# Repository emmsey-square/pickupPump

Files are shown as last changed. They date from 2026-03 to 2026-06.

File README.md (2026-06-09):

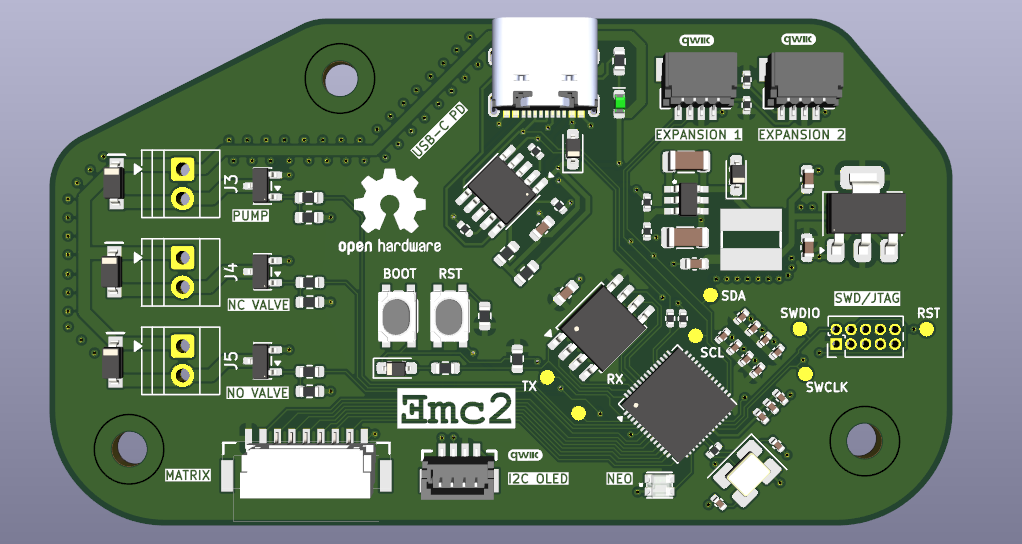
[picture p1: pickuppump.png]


#   PickupPump- a Vacuum Pickup Tool for SMD Components (In Progress)

##  Brief

I was a big fan of the Pixel Pump project by Robbin's and loving the idea, but wanting to create my own version to better suit my needs, as well as allow me to design a circuit board of my own, I started working on my very own version. 

## Design Choices 

- RP2350 for the main mcu as it's a new and interesting chip from Raspberry Pi with a very solid SDK for built for both of the RP2X chips. 
- USB-C port for power & USB paired with a CH224K USB PD sink chip to request 12V for all of the motors/pumps and a switching converter to step-down the voltage for the mcu
- JST connector for connection to an additional PCB outfitted with a 3x2 array of pushbuttons, with each one having functions such as toggling the current suction state of the pump, increasing/decreasing suction strength, etc.
- There's 3 Sparkfun Qwiic/ Stemma Qt compatible JST connectors onboard to connect to an Adafruit I2C OLED as well as to allow for expansions (ie. footswitch)
- Onboard Cortex debug header for debugging & programming

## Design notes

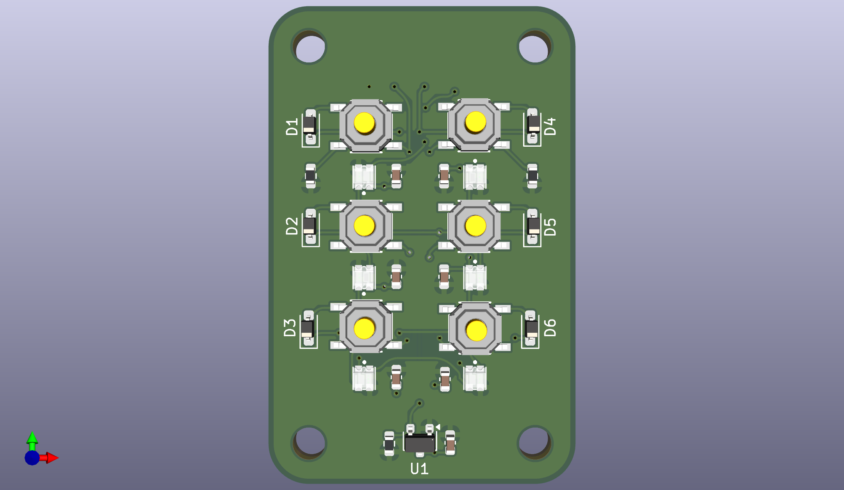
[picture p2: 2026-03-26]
pump_matrix/media/pump_matrix-front.png

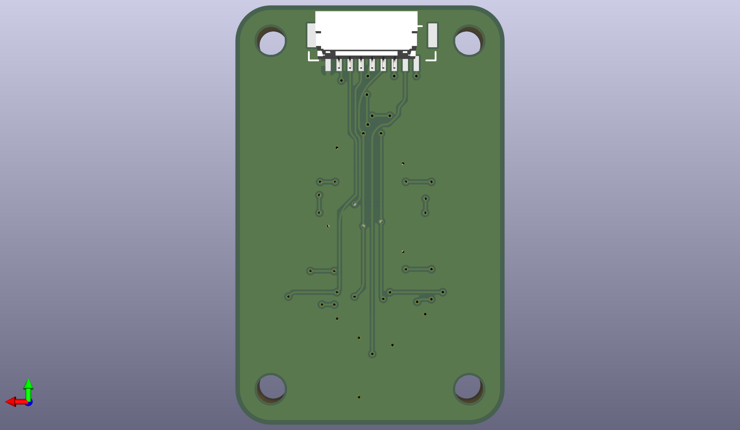
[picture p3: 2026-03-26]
pump_matrix/media/pump_matrix-back.png

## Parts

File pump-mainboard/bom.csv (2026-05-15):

Id | Designator | Footprint | Quantity | Designation | Supplier and ref
1 | TP5 | TestPoint-1.25mm | 1 | SDA
2 | C19 | C_1206_3216Metric | 1 | 4.7uF
3 | R16 | R_0402_1005Metric | 1 | 1k
4 | C10,C7,C8,C6,C9,C5,C4,C3,C11 | C_0402_1005Metric | 9 | 0.1uF
5 | L1 | Inductor_4.7x4.7mm | 1 | 15uH_5x5mm_1.0A
6 | Y1 | Crystal_SMD_EuroQuartz_MT-4Pin_3.2x2.5mm_HandSoldering | 1 | ABM8-272-T3
7 | TP1 | TestPoint-1.25mm | 1 | TX
8 | Q2,Q1,Q3 | SOT-23 | 3 | AO3400A
9 | D1,D8 | D_SOD-323_HandSoldering | 2 | 1N5819WS
10 | J3,J4,J5 | TerminalBlock_Xinya_XY308-2.54-2P_1x02_P2.54mm_Horizontal | 3 | Screw_Terminal_01x02
11 | C18 | C_1206_3216Metric | 1 | 2.2uF
12 | D4,D3,D2 | SOD-123 | 3 | 1N4007
13 | U5 | SOT23-6 | 1 | LMR14203
14 | C12,C13 | C_0402_1005Metric | 2 | 1.0uF
15 | C1,C2 | C_0402_1005Metric | 2 | 15pF
16 | R22,R23,R17,R24,R15 | R_0402_1005Metric | 5 | 10k
17 | R9,R3,R8,R11,R7,R6,R10,R4,R5 | R_0603_1608Metric | 9 | 10k
18 | J6 | JST_1x09_P1.25mm_Locking_Horizontal_SMD | 1 | BUTTON_MATRIX
19 | U2 | SOIC-8_5.3x5.3mm_P1.27mm | 1 | W25Q16JVSS
20 | U4 | SOT-223-3_TabPin2 | 1 | NCP1117-3.3
21 | J7 | JST_1x04_P1.0mm_Vertical_SMD | 1 | I2C_OLED
22 | D5 | LED_0603_1608Metric_Green | 1 | Green
23 | D7 | WS2812_2020 | 1 | WS2812B
24 | R1,R2 | R_0402_1005Metric | 2 | 27
25 | J9 | JST_1x04_P1.0mm_Horizontal_SMD | 1 | EXP2
26 | SW1 | Push_SMD_4.2x3.2mm | 1 | BOOT
27 | D6 | D_SOD-323_HandSoldering | 1 | NSR0320
28 | TP7 | TestPoint-1.25mm | 1 | RST
29 | C20 | C_0603_1608Metric | 1 | 47uF
30 | C14,C15 | C_0603_1608Metric | 2 | 10uF
31 | R20 | R_0402_1005Metric | 1 | 3.4k
32 | SW2 | Push_SMD_4.2x3.2mm | 1 | RESET
33 | R14,R12,R13 | R_0603_1608Metric | 3 | 1k
34 | TP2 | TestPoint-1.25mm | 1 | RX
35 | C16 | C_0603_1608Metric | 1 | 0.1uF
36 | J8 | JST_1x04_P1.0mm_Horizontal_SMD | 1 | EXP1
37 | U3 | SSOP-10-1EP_3.9x4.9mm_P1mm_EP2.1x3.3mm | 1 | CH224K
38 | R21 | R_0402_1005Metric | 1 | 1.02k
39 | C17 | C_0603_1608Metric | 1 | 1uF
40 | TP8 | TestPoint-1.25mm | 1 | SWDIO
41 | TP9 | TestPoint-1.25mm | 1 | SWCLK
42 | TP6 | TestPoint-1.25mm | 1 | SCL
43 | J2 | 2x05_P1.27mm | 1 | SWD
44 | U1 | QFN-56-1EP_7x7mm_P0.4mm_EP3.2x3.2mm | 1 | RP2040
45 | J1 | USB-C_16 | 1 | USB_C_Receptacle
46 | TP3 | TestPoint-1.25mm | 1 | D+
47 | TP4 | TestPoint-1.25mm | 1 | D-

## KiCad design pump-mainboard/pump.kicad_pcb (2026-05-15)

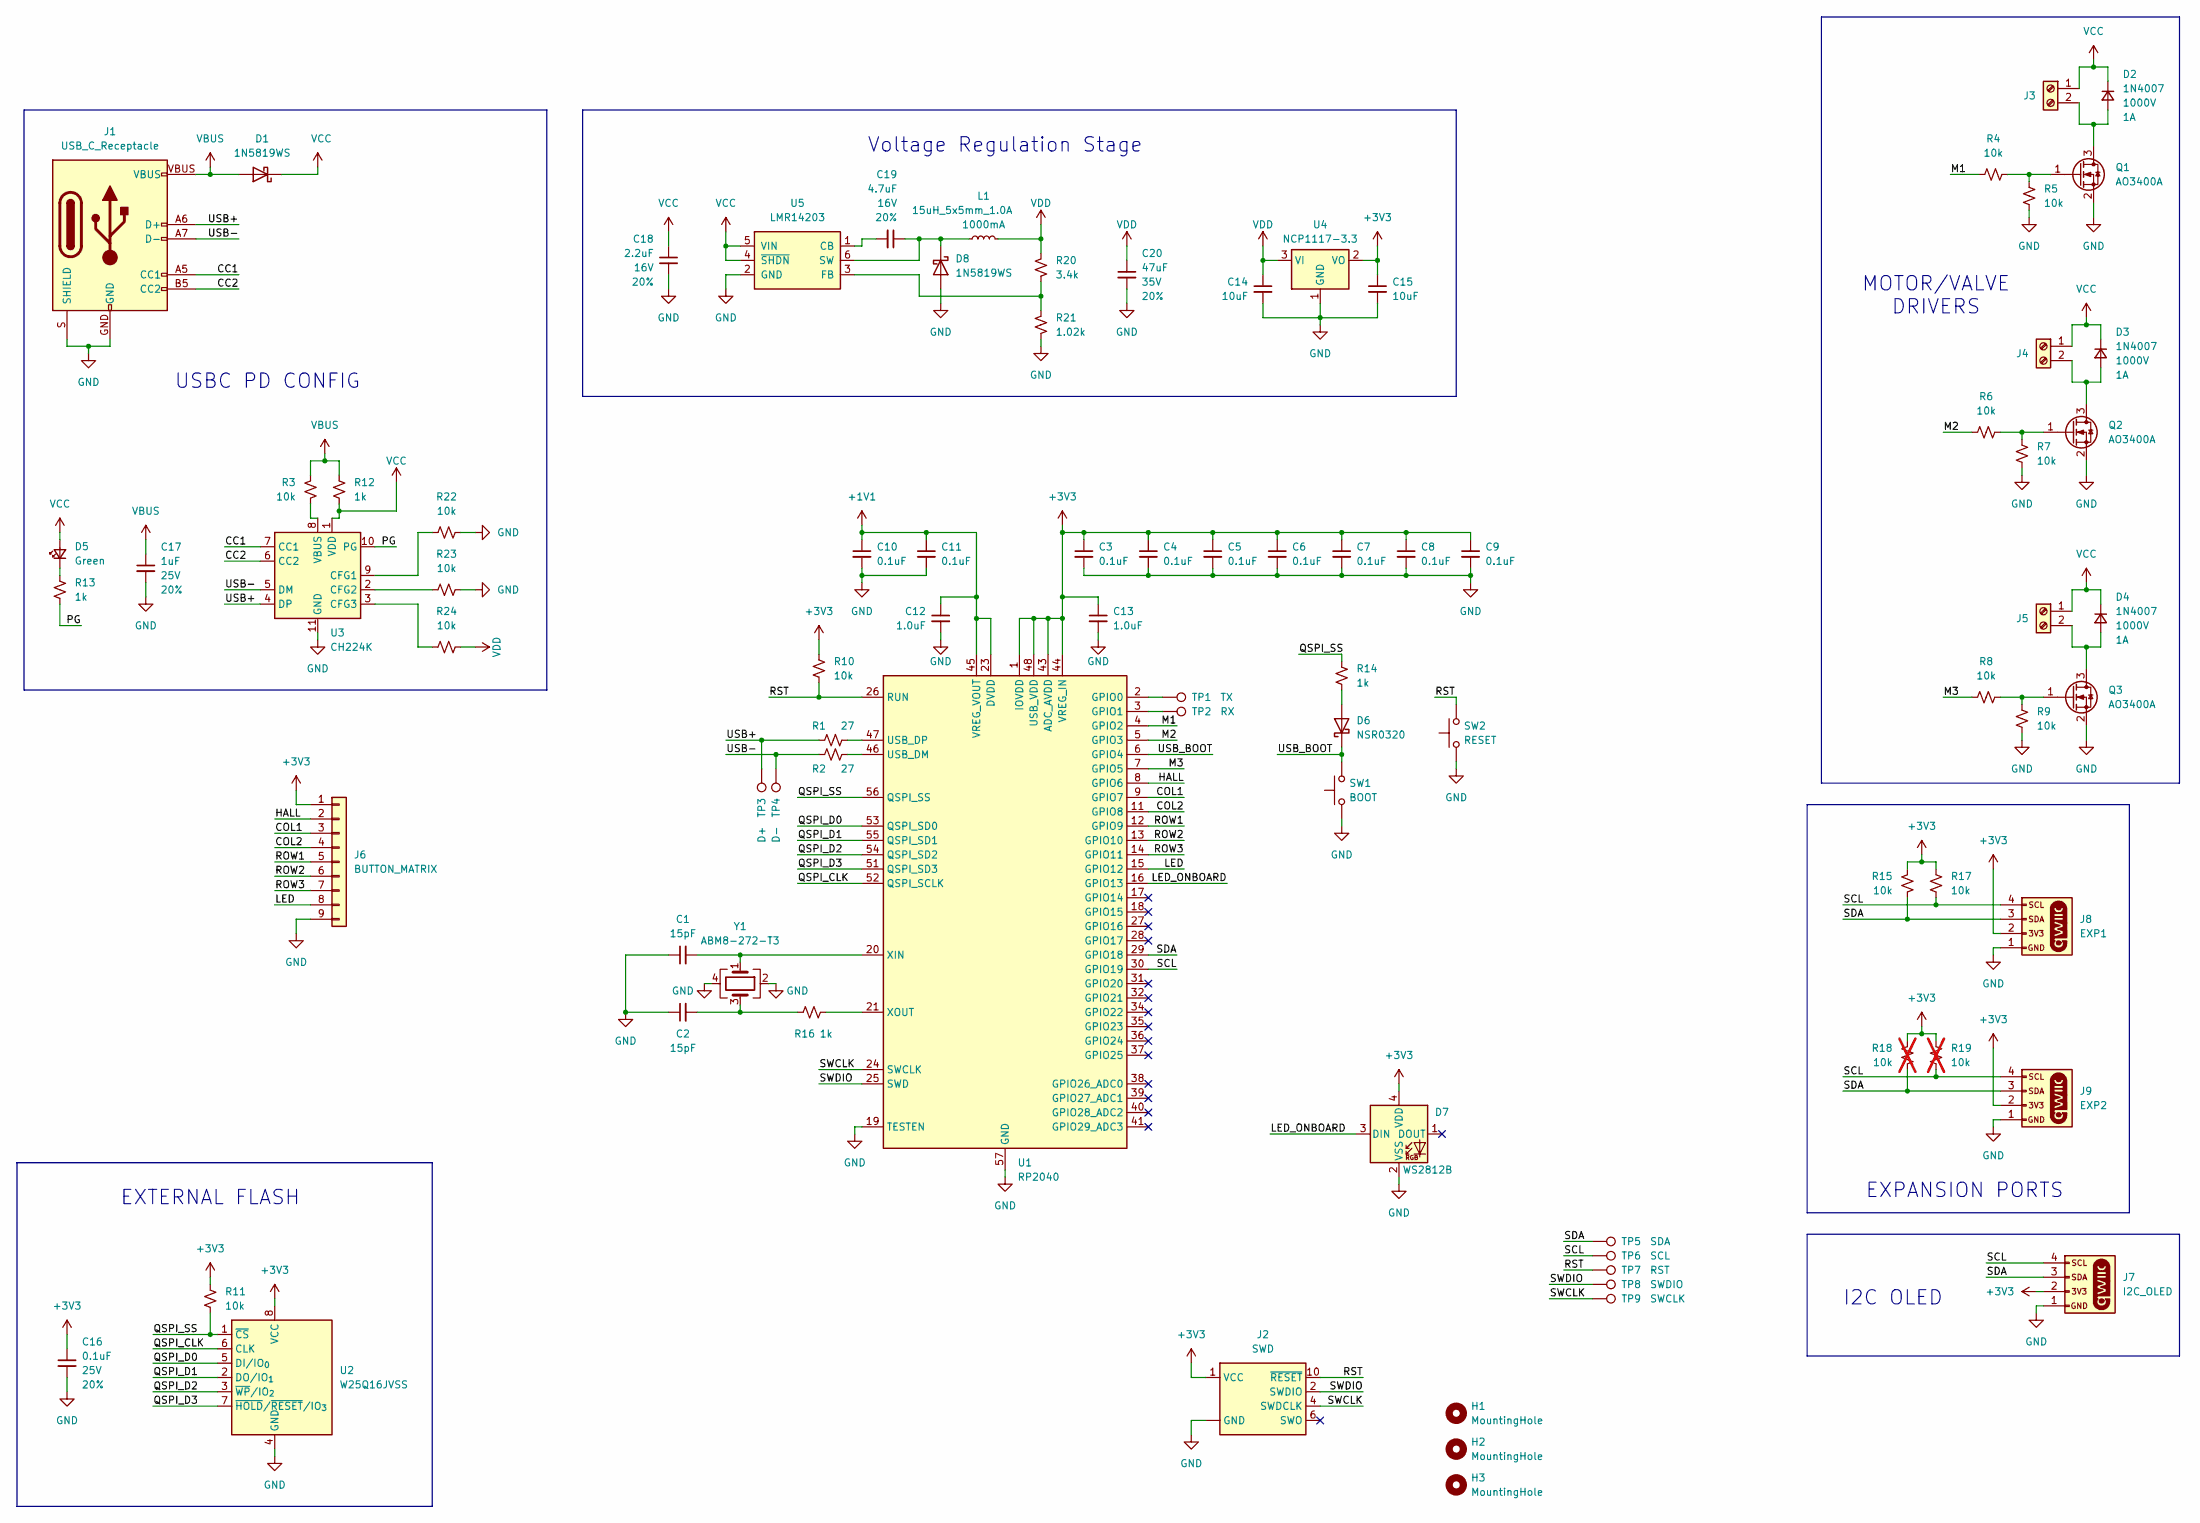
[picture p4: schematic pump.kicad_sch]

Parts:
C1, C2: 15pF; C_0402_1005Metric; Voltage 50V; Tolerance 5%
C3, C4, C5, C6, C7, C8, C9, C10, C11: 0.1uF; C_0402_1005Metric; Voltage 16V; Tolerance 10%
C12, C13: 1.0uF; C_0402_1005Metric; Voltage 16V; Tolerance 10%
C14, C15: 10uF; C_0603_1608Metric; Voltage 10V; Tolerance 20%
C16: 0.1uF; C_0603_1608Metric; Voltage 25V; Tolerance 20%
C17: 1uF; C_0603_1608Metric; Voltage 25V; Tolerance 20%
C18: 2.2uF; C_1206_3216Metric; Voltage 16V; Tolerance 20%
C19: 4.7uF; C_1206_3216Metric; Voltage 16V; Tolerance 20%
C20: 47uF; C_0603_1608Metric; Voltage 35V; Tolerance 20%
D1, D8: 1N5819WS; D_SOD-323_HandSoldering
D2, D3, D4: 1N4007; SOD-123
D5: Green; LED_0603_1608Metric_Green
D6: NSR0320; D_SOD-323_HandSoldering
D7: WS2812B; WS2812_2020
H1, H2, H3: MountingHole; MountingHole_3mm
J1: USB_C_Receptacle; USB-C_16
J2: SWD; 2x05_P1.27mm
J3, J4, J5: Screw_Terminal_01x02; TerminalBlock_Xinya_XY308-2.54-2P_1x02_P2.54mm_Horizontal
J6: BUTTON_MATRIX; JST_1x09_P1.25mm_Locking_Horizontal_SMD
J7: I2C_OLED; JST_1x04_P1.0mm_Vertical_SMD
J8: EXP1; JST_1x04_P1.0mm_Horizontal_SMD
J9: EXP2; JST_1x04_P1.0mm_Horizontal_SMD
L1: 15uH_5x5mm_1.0A; Inductor_4.7x4.7mm
Q1, Q2, Q3: AO3400A; SOT-23
R1, R2: 27; R_0402_1005Metric
R3, R4, R5, R6, R7, R8, R9, R10, R11: 10k; R_0603_1608Metric
R12, R13, R14: 1k; R_0603_1608Metric
R15, R17, R22, R23, R24: 10k; R_0402_1005Metric
R16: 1k; R_0402_1005Metric
R18, R19: 10k; R_0402_1005Metric; not fitted
R20: 3.4k; R_0402_1005Metric
R21: 1.02k; R_0402_1005Metric
SW1: BOOT; Push_SMD_4.2x3.2mm
SW2: RESET; Push_SMD_4.2x3.2mm
TP1: TX; TestPoint-1.25mm
TP2: RX; TestPoint-1.25mm
TP3: D+; TestPoint-1.25mm
TP4: D-; TestPoint-1.25mm
TP5: SDA; TestPoint-1.25mm
TP6: SCL; TestPoint-1.25mm
TP7: RST; TestPoint-1.25mm
TP8: SWDIO; TestPoint-1.25mm
TP9: SWCLK; TestPoint-1.25mm
U1: RP2040; QFN-56-1EP_7x7mm_P0.4mm_EP3.2x3.2mm
U2: W25Q16JVSS; SOIC-8_5.3x5.3mm_P1.27mm
U3: CH224K; SSOP-10-1EP_3.9x4.9mm_P1mm_EP2.1x3.3mm
U4: NCP1117-3.3; SOT-223-3_TabPin2
U5: LMR14203; SOT23-6
Y1: ABM8-272-T3; Crystal_SMD_EuroQuartz_MT-4Pin_3.2x2.5mm_HandSoldering

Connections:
+1V1: C10.1, C11.1, C12.1, U1.23 (DVDD), U1.45 (VREG_VOUT), U1.50 (DVDD)
+3V3: C3.1, C4.1, C5.1, C6.1, C7.1, C8.1, C9.1, C13.1, C15.1, C16.1, D7.4 (VDD), J2.1 (VCC), J6.1, J7.2, J8.2, J9.2, R10.2, R11.2, R15.2, R17.2, R18.2, R19.2, U1.1 (IOVDD), U1.10 (IOVDD), U1.22 (IOVDD), U1.33 (IOVDD), U1.42 (IOVDD), U1.43 (ADC_AVDD), U1.44 (VREG_IN), U1.48 (USB_VDD), U1.49 (IOVDD), U2.8 (VCC), U4.2 (VO)
/CC1: J1.A5 (CC1), U3.7 (CC1)
/CC2: J1.B5 (CC2), U3.6 (CC2)
/COL1: J6.3, U1.9 (GPIO7)
/COL2: J6.4, U1.11 (GPIO8)
/HALL: J6.2, U1.8 (GPIO6)
/LED: J6.8, U1.15 (GPIO12)
/LED_ONBOARD: D7.3 (DIN), U1.16 (GPIO13)
/M1: R4.1, U1.4 (GPIO2)
/M2: R6.1, U1.5 (GPIO3)
/M3: R8.1, U1.7 (GPIO5)
/PG: R13.1, U3.10 (PG)
/QSPI_CLK: U1.52 (QSPI_SCLK), U2.6 (CLK)
/QSPI_D0: U1.53 (QSPI_SD0), U2.5 (DI/IO_{0})
/QSPI_D1: U1.55 (QSPI_SD1), U2.2 (DO/IO_{1})
/QSPI_D2: U1.54 (QSPI_SD2), U2.3 (~WP/IO_{2})
/QSPI_D3: U1.51 (QSPI_SD3), U2.7 (~HOLD/~RESET/IO_{3})
/QSPI_SS: R11.1, R14.2, U1.56 (QSPI_SS), U2.1 (~CS)
/ROW1: J6.5, U1.12 (GPIO9)
/ROW2: J6.6, U1.13 (GPIO10)
/ROW3: J6.7, U1.14 (GPIO11)
/RST: J2.10 (~RESET), R10.1, SW2.2, TP7.1, U1.26 (RUN)
/SCL: J7.4, J8.4, J9.4, R17.1, R19.1, TP6.1, U1.30 (GPIO19)
/SDA: J7.3, J8.3, J9.3, R15.1, R18.1, TP5.1, U1.29 (GPIO18)
/SWCLK: J2.4 (SWDCLK), TP9.1, U1.24 (SWCLK)
/SWDIO: J2.2 (SWDIO), TP8.1, U1.25 (SWD)
/USB+: J1.A6 (D+), J1.B6 (D+), R1.1, TP3.1, U3.4 (DP)
/USB-: J1.A7 (D-), J1.B7 (D-), R2.1, TP4.1, U3.5 (DM)
/USB_BOOT: D6.1 (K), SW1.2, U1.6 (GPIO4)
GND: C1.1, C2.1, C3.2, C4.2, C5.2, C6.2, C7.2, C8.2, C9.2, C10.2, C11.2, C12.2, C13.2, C14.2, C15.2, C16.2, C17.2, C18.2, C20.2, D7.2 (VSS), D8.2 (A), J1.GND, J1.S (SHIELD), J2.3 (GND), J2.5 (GND), J2.9 (GND), J6.9, J7.1, J8.1, J9.1, Q1.2 (S), Q2.2 (S), Q3.2 (S), R5.1, R7.1, R9.1, R21.1, R22.2, R23.2, SW1.1, SW2.1, U1.19 (TESTEN), U1.57 (GND), U2.4 (GND), U3.11 (GND), U4.1 (GND), U5.2 (GND), Y1.2, Y1.4
unnamed: C2.2, R16.1, Y1.3
unnamed: D2.2 (A), J3.2, Q1.3 (D)
unnamed: D3.2 (A), J4.2, Q2.3 (D)
unnamed: D4.2 (A), J5.2, Q3.3 (D)
unnamed: D5.1 (K), R13.2
unnamed: D6.2 (A), R14.1
unnamed: C19.1, D8.1 (K), L1.1, U5.6 (SW)
unnamed: Q1.1 (G), R4.2, R5.2
unnamed: Q2.1 (G), R6.2, R7.2
unnamed: Q3.1 (G), R8.2, R9.2
unnamed: TP1.1, U1.2 (GPIO0)
unnamed: TP2.1, U1.3 (GPIO1)
unnamed: R2.2, U1.46 (USB_DM)
unnamed: R1.2, U1.47 (USB_DP)
unnamed: C1.2, U1.20 (XIN), Y1.1
unnamed: R16.2, U1.21 (XOUT)
unnamed: R22.1, U3.9 (CFG1)
unnamed: R23.1, U3.2 (CFG2)
unnamed: R24.1, U3.3 (CFG3)
unnamed: R3.1, U3.8 (VBUS)
unnamed: C19.2, U5.1 (CB)
unnamed: R20.1, R21.2, U5.3 (FB)
VBUS: C17.1, D1.2 (A), J1.VBUS, R3.2, R12.2
VCC: C18.1, D1.1 (K), D2.1 (K), D3.1 (K), D4.1 (K), D5.2 (A), J3.1, J4.1, J5.1, R12.1, U3.1 (VDD), U5.4 (~SHDN), U5.5 (VIN)
VDD: C14.1, C20.1, L1.2, R20.2, R24.2, U4.3 (VI)

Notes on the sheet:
I2C OLED
Voltage Regulation Stage
USBC PD CONFIG
EXPANSION PORTS
MOTOR/VALVE DRIVERS
EXTERNAL FLASH

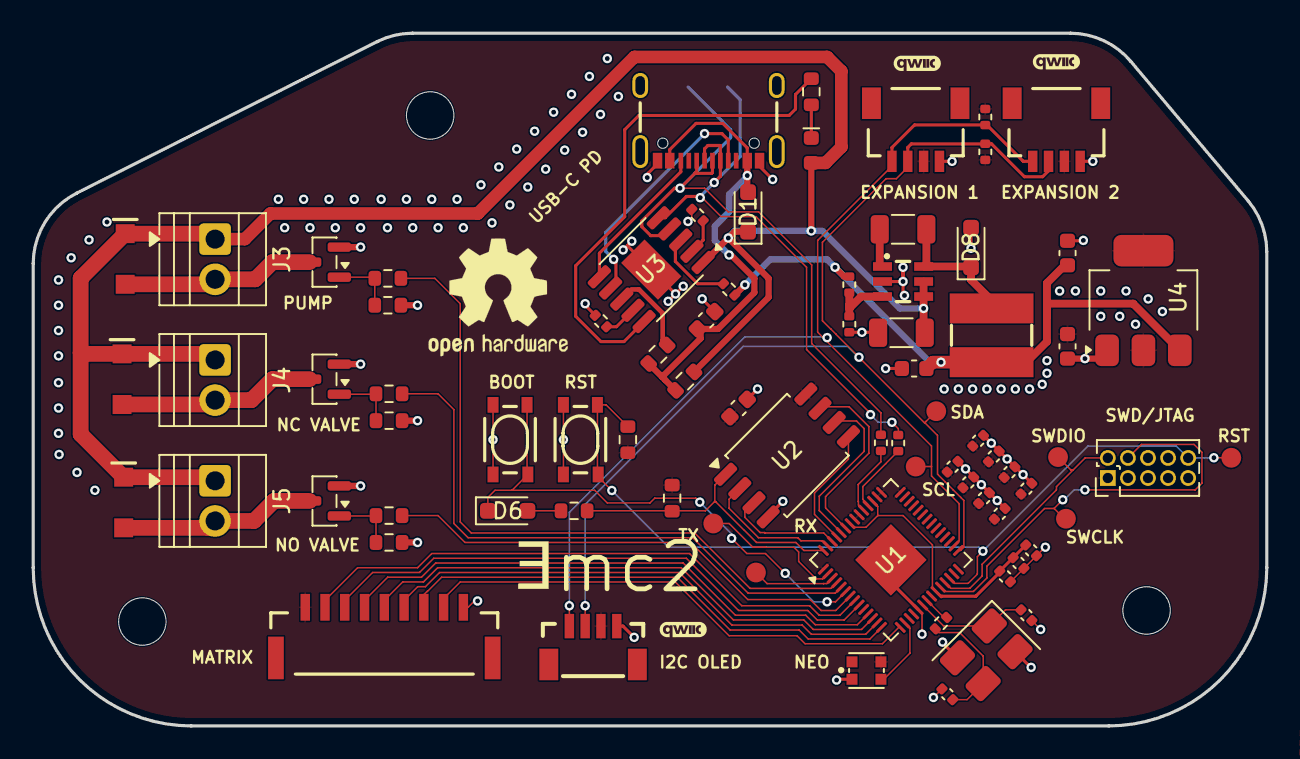
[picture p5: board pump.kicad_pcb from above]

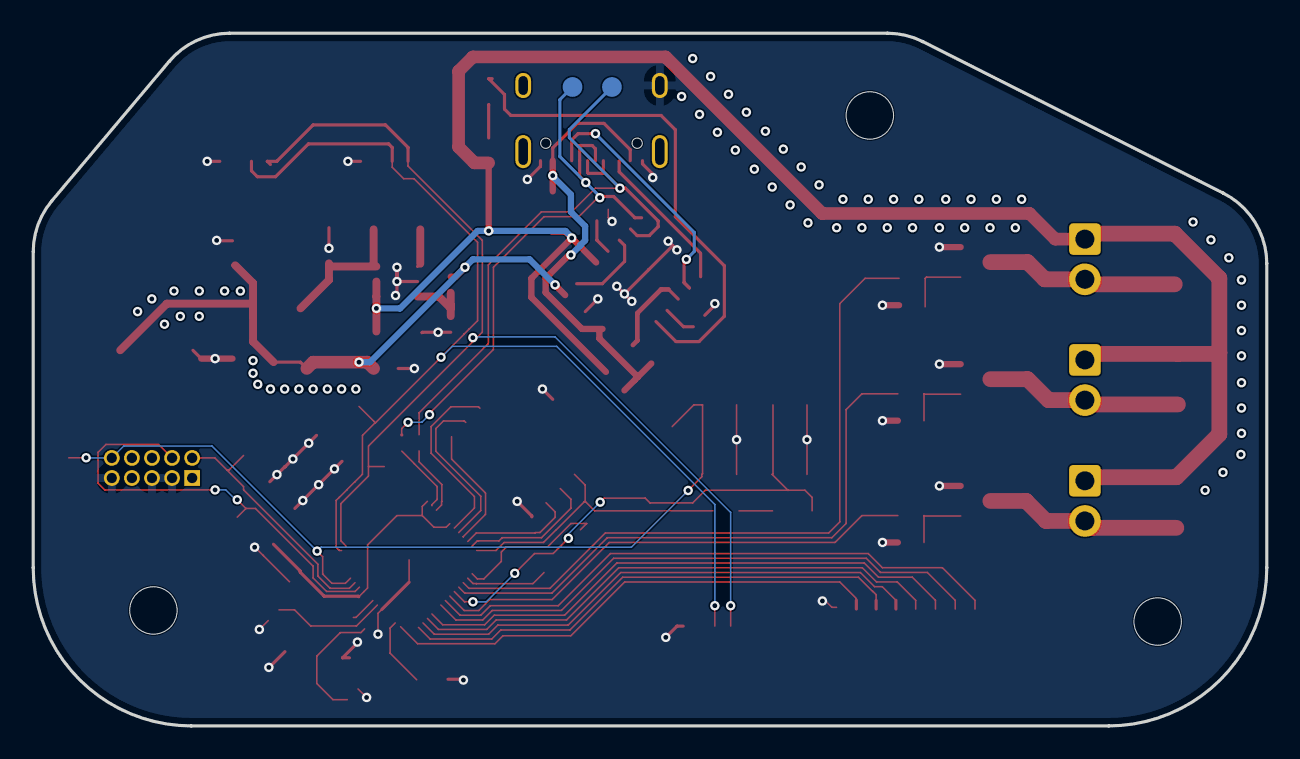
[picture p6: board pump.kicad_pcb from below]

Board: 2 copper layers, 78.0 x 43.8 mm, 83 parts (2 on the bottom side), 56 nets.

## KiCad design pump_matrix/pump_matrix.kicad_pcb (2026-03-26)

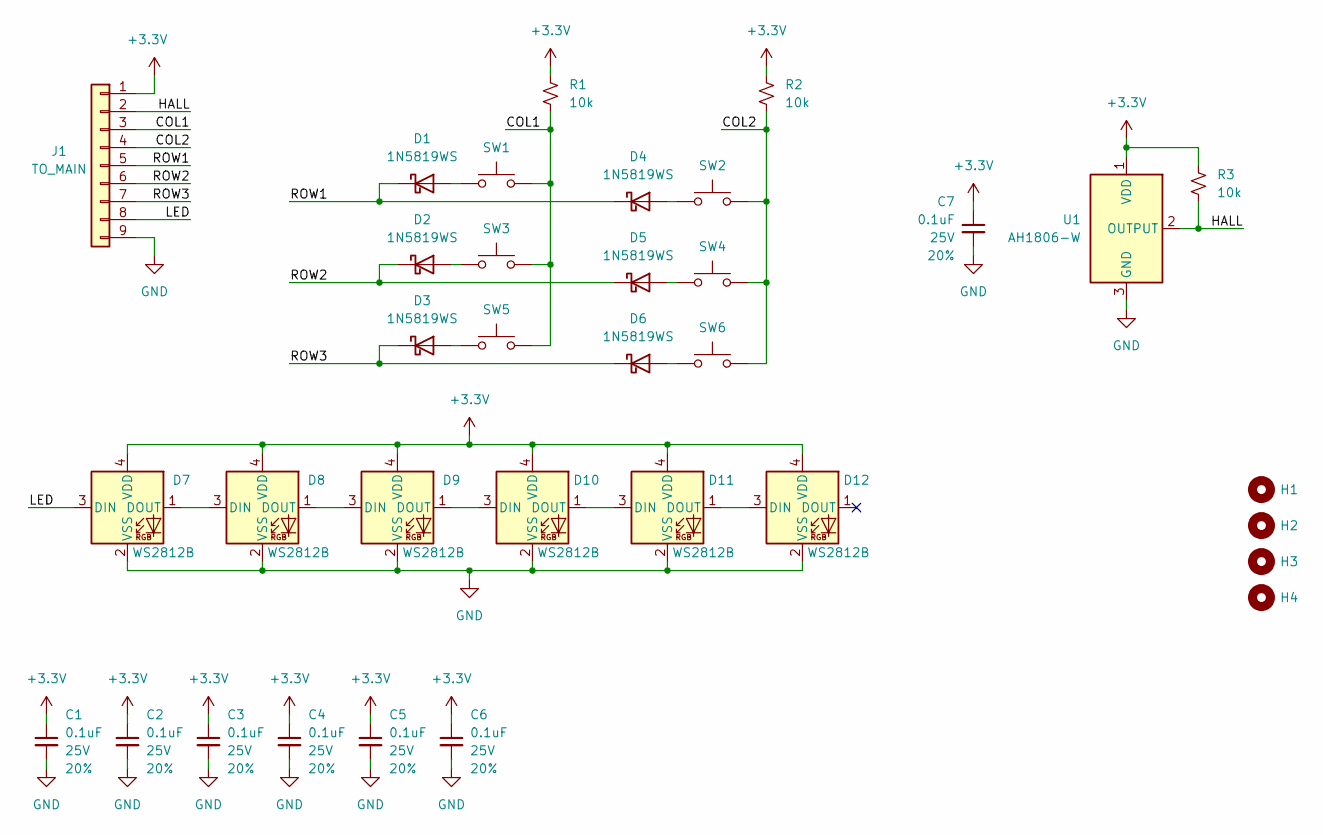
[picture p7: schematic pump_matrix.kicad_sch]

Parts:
C1, C2, C3, C4, C5, C6, C7: 0.1uF; C_0603_1608Metric; Voltage 25V; Tolerance 20%
D1, D2, D3, D4, D5, D6: 1N5819WS; D_SOD-323_HandSoldering
D7, D8, D9, D10, D11, D12: WS2812B; WS2812_2020
H1, H2, H3, H4: MountingHole; MountingHole_3.2mm_M3
J1: TO_MAIN; JST_1x09_P1.25mm_Locking_Horizontal_SMD
R1, R2, R3: 10k; R_0603_1608Metric
SW1, SW2, SW3, SW4, SW5, SW6: SMD_5.2x5.2mm_h2.5mm; Push_SMD_5.2x5.2mm_h2.5mm
U1: AH1806-W; SC-59

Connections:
+3.3V: C1.1, C2.1, C3.1, C4.1, C5.1, C6.1, C7.1, D7.4 (VDD), D8.4 (VDD), D9.4 (VDD), D10.4 (VDD), D11.4 (VDD), D12.4 (VDD), J1.1, R1.2, R2.2, R3.2, U1.1 (VDD)
/COL1: J1.3, R1.1, SW1.2, SW3.2, SW5.2
/COL2: J1.4, R2.1, SW2.2, SW4.2, SW6.2
/HALL: J1.2, R3.1, U1.2 (OUTPUT)
/LED: D7.3 (DIN), J1.8
/ROW1: D1.1 (K), D4.1 (K), J1.5
/ROW2: D2.1 (K), D5.1 (K), J1.6
/ROW3: D3.1 (K), D6.1 (K), J1.7
GND: C1.2, C2.2, C3.2, C4.2, C5.2, C6.2, C7.2, D7.2 (VSS), D8.2 (VSS), D9.2 (VSS), D10.2 (VSS), D11.2 (VSS), D12.2 (VSS), J1.9, U1.3 (GND)
unnamed: D1.2 (A), SW1.1
unnamed: D2.2 (A), SW3.1
unnamed: D3.2 (A), SW5.1
unnamed: D4.2 (A), SW2.1
unnamed: D5.2 (A), SW4.1
unnamed: D6.2 (A), SW6.1
unnamed: D7.1 (DOUT), D8.3 (DIN)
unnamed: D8.1 (DOUT), D9.3 (DIN)
unnamed: D9.1 (DOUT), D10.3 (DIN)
unnamed: D10.1 (DOUT), D11.3 (DIN)
unnamed: D11.1 (DOUT), D12.3 (DIN)

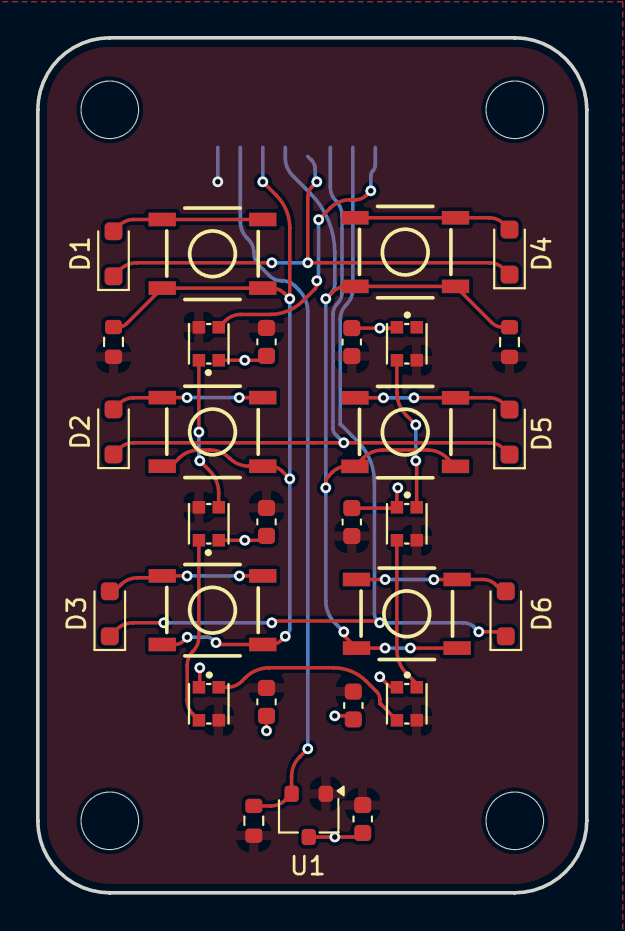
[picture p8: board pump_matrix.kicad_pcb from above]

Board: 2 copper layers, 30.5 x 47.5 mm, 34 parts (1 on the bottom side), 20 nets.
